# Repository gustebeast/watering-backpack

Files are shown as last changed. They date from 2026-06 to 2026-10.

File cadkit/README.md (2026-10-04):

# cadkit

Small, project-agnostic helpers for **parametric 3D-printing with CadQuery** — the
shared code behind a set of printable-hardware projects. Vendored into each project via
`git subtree`, so every project repo stays self-contained.

## Layout

```
cadkit/
  fasteners.py       M2/M4 hole + heat-set-insert geometry (self-tap now, insert later);
                     one FastenerSpec API, print-undersize aware
  threads.py         self-supporting 45° FDM screw threads (read THREADS_README.md first)
  joinery.py         printable mortise-and-tenon slide joints (read JOINERY_README.md)
  supports.py        teardrop + 45° wall-ramp support for short SIDEWAYS bosses
                     (horizontal cylinder off a wall, printed -Z→+Z)
  holes.py           teardrop_hole() — cutter for SIDEWAYS round holes: 45°
                     teardrop ceiling replaces the sagging round top; round
                     lower half untouched (pins/rods bear as in a round bore)
  printing.py        FDM minimum-material rule, counted in WHOLE BEADS (no
                     buffer — Arachne fills exact nozzle multiples cleanly).
                     min_wall(nozzle) = one bead = the hard floor;
                     min_wall(nozzle, beads=2) = 1.6 at 0.8 = the QUALITY
                     target. Aim at two; drop to one only in a tight room.
  contact.py         minimal-contact rub features: contact_rib_size(nozzle)
                     = exactly one nozzle (width AND proud; Arachne keeps
                     exact-nozzle lines); contact_ring() = ring + teardrop tail
  pcb.py             PCB mounting (one-screw cradle) + drawing-accurate JST headers
  board_geom.py      a ROUTED KiCad board as CAD solids: laminate, part bodies,
                     through-hole tails, mated plugs, connector mouths, silk
                     (read PCB_README.md first)
  board_check.py     gate: is the board the CAD draws the board that was routed?
  kicad_geom.py      KiCad-side exporter (run under KiCad's Python): routed
                     .kicad_pcb -> <board>.geom.json, the file board_geom reads
  kicad_silk.py      KiCad-side labeller: board name + revision, test-pad nets,
                     connector pinouts, each only where it fits
  pcbflow/           MAKE a board from code: one `elec/<board>.py` (SKiDL circuit +
                     placements) -> placed, autorouted, DRC-clean, labelled board,
                     its geom file and its fab package. gen.py (generator helpers),
                     layout/route/finish/verify/close_last, fab_package.py, example/
  PCB_QUALITY.md     THE standard PCB validation pass and the one place PCB lessons
                     go: automated rules (pcbflow/quality.py -- supply choke points
                     and drop, bypass capacitors, matched pairs, pinout citations)
                     plus a manual checklist each board signs with evidence
  step_export.py     export_step(obj, path) — names the STEP product after the file
  overlap_check.py   parallel interpenetration gate (wrap in tools/check_overlaps.py)
  cq_colors.py       hex / 0..255 / name -> cq.Color, for baking colours into a STEP
  freecad/           OPTIONAL FreeCAD viewer hub (isolated so the core needs no FreeCAD)
    __init__.py        `from cadkit.freecad import show`
  tools/
    agent_sync.py    dev-only multi-agent git-worktree coordination CLI (run as a script)
```

The **core** modules depend only on CadQuery/OCP — no FreeCAD. The FreeCAD-specific
viewer lives in `cadkit.freecad` and is opt-in; `show()` never raises, so viewer trouble
can't break a build.

## Use

```python
from cadkit.fasteners import cut_anchor, M2, M4
from cadkit.threads import cut_thread, threaded_rod
from cadkit.joinery import PrintSpec, joint
from cadkit.step_export import export_step
from cadkit.overlap_check import run
from cadkit import cq_colors
from cadkit.freecad import show          # optional; opens/refreshes a FreeCAD viewer tab
```

A project vendors cadkit at its repo root and runs its build via `python -m` from there,
so `cadkit` is importable with no path hack.

## Vendoring into a project

```
git remote add cadkit https://github.com/gustebeast/cadkit
git subtree add  --prefix=cadkit cadkit main --squash    # first time
git subtree pull --prefix=cadkit cadkit main --squash    # to update later
```

## Changing cadkit — you MUST propagate to every consumer

cadkit is **vendored** (copied) into each project, so the copies **drift** the
moment the canonical repo changes — nothing forces them identical. Therefore a
cadkit change is not *done* when you commit it; it is done when every consumer
project has been re-pulled. **Never edit a project's vendored `cadkit/` in place** —
edit the canonical repo, then propagate.

The whole process is one command — **run it from the standalone canonical cadkit
checkout, after committing your change there** (it refuses to run from a project's
vendored copy):

```
py -3.12 tools/propagate.py        # pushes canonical, then re-pulls into every consumer
```

It pushes the canonical to its upstream (one source of truth), auto-discovers
every sibling project that vendors cadkit, and re-pulls the subtree into each.
A project with a **dirty** working tree is **skipped** (never auto-stashed) and
reported — commit or stash there, then re-run. The exit code is the number of
consumers *not* in sync, so `propagate.py` doubles as a gate: **0 means every
project is current.** Use `--dry-run` to preview, `--no-push` to pull only.

(The manual equivalent, per project, is `git fetch cadkit main &&
git subtree pull --prefix=cadkit cadkit main --squash` — but do not hand-run it
across N repos; that is exactly the step people forget, which is what drift is.)

See `THREADS_README.md` and `JOINERY_README.md` before changing threads or joinery —
both encode FDM-specific rules that fail silently if broken. See `PCB_README.md` before
putting a circuit board in a project: it holds the KiCad ⇄ CAD loop and the board-design
guidance (mounting, connectors, layout, pre-order checks) that no tool can enforce.

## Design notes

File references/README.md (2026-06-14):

# Reference geometry

Drop reference STEP files here. They're imported by `src/viz.py` and
appear in `assembly.step` for dimensional verification — they're never
exported as printable parts.

Expected files:

| File | Source | Purpose |
|---|---|---|
| `makita_battery.step` | [GrabCAD — Makita LxT 18V 5A Battery](https://grabcad.com/library/makita-lxt-18v-5a-battery-1) | Battery dock interface reference |

Files in this directory are not committed (large binary; license varies
by source). Each contributor downloads them from the linked source.

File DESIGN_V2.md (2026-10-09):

# Watering Backpack v2 — Architecture

Status: **architecture settled, detailed design not started.** Written 2026-10-03.

v1 worked but had three compounding problems: the pump lost prime constantly, sand
from the pumice wrecked flow and threatened the pump, and the wiring was hand-soldered
flying leads. This records what v2 changes and — more importantly — *why*, since most
of these decisions came from measurements that are easy to lose.

---

## The v1 problems, diagnosed

### Priming

**Symptom.** After ingesting air, the pump would not re-prime. Recovery required
forcing water into the green line by mouth, repeatedly.

**Root cause.** The 4-way valve had to be reachable while wearing the pack, so it sat
at chest height. That forced the water path up, down, and up again. A diaphragm pump
moves air poorly, so re-priming means evacuating the whole line — but every dip holds
a water slug, and each slug adds static head the weak air-pumping cannot overcome.
Pouring water in worked because it restored a continuous column instead of making the
pump fight slug by slug.

**The thing that reframes it:** air ingestion is not a fault to prevent. The watering
method (fill the liner, then drain it dry) ingests air at the end of *every single
retract*, by design. Re-priming is a routine operation, not an exception.

### Filtering

Pumice fines in retract (the worse case) and fertilizer sediment in dispense. The v1
filter was unreachable while worn, and sat next to electronics so it could not be
rinsed. Cleaning it drained the pump, which then would not re-prime — the two problems
fed each other.

### Flow geometry

3/8" ID tubing on a 3.0 GPM pump is **8.7 ft/s**; suction lines want 2–3 ft/s. Four
5/8"→3/8" reducers compounded it. Roughly 6 psi of avoidable friction, and on the
suction side that directly erodes the margin against cavitation.

---

## v2 decisions

### 1. Two pumps, no reversing valve

Two Seaflo 42-series pumps in anti-parallel, sharing both lines through tees:

```
                      ┌─── Pump A (tank→pot) ───┐
  Tank ──── tee ──────┤                         ├────── tee ──── Green line ──── wand
                      └─── Pump B (pot→tank) ───┘
```

One wand. The idle pump's internal check valves seal its branch when **nothing is
running** — validated in the v1 BOM note: *"diaphragm pump check-valves block flow
when off, no siphon."*

⚠ **That note does not cover the case this arrangement actually creates, and the
sentence above used to be written as if it did.** The v1 note is about a STATIC
system: gravity trying to push water out of a wand below the tank, which a check
valve holds. Anti-parallel is not that case. Plumbed head to tail, a running pump A
raises pressure at the tee that is pump B's *inlet* and lowers it at the tee that is
pump B's *outlet* — a differential in pump B's **forward** direction, which is the
direction its check valves exist to pass. Two pumps in *parallel* would see the
reverse differential the v1 note describes; anti-parallel inverts it.

The risk is therefore not a siphon but a **bypass**: part of pump A's flow
short-circuiting through pump B's chambers instead of going down the wand. What
limits it is that a stopped diaphragm pump is a poor flow path, and nothing here has
measured how poor. **Built without a check valve, deliberately** — the cure costs
pressure drop, two more joints on a system whose headline problem is priming, and two
more air traps, against a fault that costs flow rate rather than function. The
measurement that would settle it is written down in `WORK_V2_PUNCHLIST.md` finding 12
so it does not have to be re-derived on the day.

**Why not reverse the pump:** a diaphragm pump's check valves are passive. Reversing
motor polarity spins the motor backwards but does not reverse flow. No diaphragm pump
is bidirectional; this is structural, not a sourcing problem.

**Why not solenoid valves:** cheap solenoids are pilot-operated and need 3–7 psi of
differential to open. At the moment of switching the differential is zero, so they
never open. Direct-acting valves work at zero differential but are expensive and draw
continuous holding power at this bore.

**Why not motorize the existing Farady X-port valve:** it is a car AC/heater valve,
designed for ~2 actuations per year. v2 would actuate it ~60 times per watering
session. It is already stiff enough to be hard to turn by hand after sitting, and dry
lube did not fix it — that is a duty-cycle mismatch of ~3 orders of magnitude, not a
lubrication problem. Motorising it relocates the failure to worn seats, stall
currents, and a sheared coupler. A purpose-built motorized ball valve is the same
ball-and-seat technology and would need two 3-way units (a 5/8"-barb motorized 4-way
X-port is not readily sourced), which needs the same two tees anyway.

Cost: **+$75, +~1.2 kg**, accepted.

**Open risk:** each tee has a branch to the idle pump. Those stay water-filled via the
check valves, but must be oriented so they cannot collect an air pocket. This system
ingests air every cycle, so air traps matter more here than in a normal install.

### 2. Flip the orientation — tank above pumps

Not mainly about flooding the inlet. A **dry diaphragm chamber primes terribly; a wet
one primes well.** Tank-above-pump keeps the chambers wet between sessions, which
attacks the root of the re-prime problem.

Note the limit: with the pumps fed from the tank only in dispense, retract still lifts
from pots at knee height (~1.5–2 ft). Flipping solves dispense priming structurally
and makes retract priming merely easier.

**Deck height is set by a hose, not by the pumps.** The rails sit at z=150, not
the ~124 that merely clears the 119 mm pumps. Pump B's inner port has its swivel
nut reaching into pump A's half, so that line cannot run forward at port height
without passing through pump A — measured at 8190 mm3 by `tools/check_plumbing.py`.
Its only way out is OVER the pumps, and a 19 mm line needs 9.5 mm either side of
its centreline. The alternative was a ~21 mm gap *between* the pumps, which buys
the same clearance out of WIDTH; width is the scarce axis (the posts already
overhang the 340 mm shelf) and height is not, so it came out of height.

### 3. Tank outlet — Uniseal

The Scepter's 44 mm opening is too small to get a hand inside, so a conventional
bulkhead (nut on the inside) is out. A **Uniseal** installs entirely from outside:
drill, work the seal in, push rigid pipe through. Standard on IBC totes and sealed
barrels, and holds far more head than 5 gallons. Scepter walls are flat enough.

Fallback if the Uniseal does not suit: keep the top-routed dip tube and add a **foot
valve** at its bottom so the column cannot drain back. Less robust — a slightly leaky
foot valve loses prime overnight — but needs no modification to the tank.

### 4. Filter — two bought strainers at the tees, self-backflushing

**DECIDED 2026-10-05.** This section used to specify a *printed*, sealed,
self-backflushing screen on the green line, and `src/line_filter.py` built it. It is
now **the two 50-mesh inlet strainers that came with the pumps, one at each tee** —
`WORK_V2_PUNCHLIST.md` findings 13 and 13a, both closed. The argument below did not
change; what changed is that the owner backflushed one of the stock strainers and it
cleared itself, which is this section's own argument made about the *exact part*
rather than about a part like it. The printed screen, its housing, and the
`test_screen_slice` coupon are gone — recorded in `bom_consolidated.md` §7b and its
*Dropped* list.

#### Why a filter on the green line at all, and why it self-cleans

The green line is the only line that is *both* bidirectional *and* connected to every
dirty source:

| operation | path | filter direction |
|---|---|---|
| retract from pot | sand → filter → pump → tank | filtering |
| fertilizer draw | fertilizer → filter → pump → tank | filtering |
| dispense | tank (pre-filtered) → pump → filter → pot | **backflushing** |

So the pump never sees unfiltered water, and **every fill backflushes what the
previous drain collected.** Sand migrates forward one pot per cycle — pumice fines
returning to pumice — and never accumulates. No cleaning step between pots.

**Geometry is constrained by backflushing, and the stock strainer satisfies it.** A
Y-strainer or spin-down collects debris in a sump *below* the flow path, deliberately,
so reverse flow does not re-entrain it — those filter and never self-clean. What is
needed is a straight-through cylindrical screen with no dead volume, which is exactly
what the 51S01 is, and the owner's backflush test is the proof rather than the
expectation.

#### Where they go, and which way round

One at each tee, inline on the tee's third leg: the green tee's leg down to the wand,
the tank tee's leg up to the Uniseal. Not dangling on the hose — that snags and adds
a suction-side joint that can pull air.

⚠ **They are DIRECTIONAL, and the handedness is set by the paragraphs above.** The
51S01 filters male→female and cleans female→male (owner, measured on the part). The
filter must collect on the drain and be swept clean on the fill, so the **male** end
faces whatever each strainer protects against — and that is not the same side at the
two tees:

- **Green tee: male toward the POT.** Dirty water enters at the wand on retract, so
  retract collects and dispense sweeps the debris back out toward the pot.
- **Tank tee: male toward the TANK.** What that one protects is **pump A**, and what
  threatens pump A is the tank's own settled sediment, drawn in on fill. So fill
  collects and drain sweeps it back into the tank to settle out again.

Either one fitted backwards runs its collecting stroke as a cleaning stroke and sweeps
the debris *toward* the pump instead of away from it.

Both therefore show their **female** end to the tee, and that is what makes the
fittings come out even — one male-threaded tee leg screws straight into each, with no
adapter and no hose stub. Worked through, with the fitting on each end, in finding 13a.

#### What the change costs, named

- **50 mesh instead of ≈60 mesh.** The printed screen's 0.25 mm slots were slightly
  finer than the strainers' 50 mesh. Accepted: the thing being excluded is pumice sand
  and fertilizer grit, and one mesh step does not decide whether the pump survives it.
- **Two tees have to be bought** — barb × barb × 1/2"-14 MNPT, 1/2" barbs. They were
  never on the BOM anyway (finding 14, closed), so this decision is what finally put
  them there rather than an extra cost it created.
- **The strainers' length is not measured, and it now matters.** Each one occupies
  inline length on its tee's third leg. The model gives the green leg 124 mm of
  straight and the tank leg about 100 mm. Finding 16.
- **No longer sealed.** The printed housing was deliberately unopenable, because a
  threaded joint on a suction line is an air-leak path and priming is the headline
  problem. Each strainer adds two threaded joints on a suction line. Accepted, and it
  is the real cost of this change: they are tapered pipe threads with tape, not the
  twist-off cap the argument was against, and the system already re-primes every cycle
  by design. Watch these two joints first if priming regresses.

**Spigot water** goes to the tank through its own separate fill line and bypasses the
filter entirely; municipal water is clean enough. Revisit only if filling from a rain
barrel.

**Barbs: 3/8" on the pot side** (fixed by the inner-pot tube), **1/2" everywhere
else**. The transition is the owned McMaster 5346K56 (1/2 NPT female × 3/8" barb) on
the green strainer's male end — the job the printed housing used to do. (This said
5/8" until 2026-10-05; see §5.)

### 5. Tubing — 1/2" everywhere except the probe

The 3/8" constraint is only the probe that goes down the inner-pot channel, and that
one is the owner's: *"the green line has to stay 3/8 but all the other lines can
change."* The main run is **1/2"**.

⚠ **This section used to read "5/8" everywhere except the probe" and it was wrong
by the time anyone read it.** The 5/8" was an inference from the friction argument
— nobody ever asked for it — and §2 of `bom_consolidated.md` had already decided
the other way, with reasons, when it chose the pump-port fitting. **The owner has
now bought that fitting**: SEAFLO SFFN1-1220-01, 1/2"-14 FNPT × **1/2" barb**,
five of them, four fitted and one spare. A 5/8" tube does not grip a 1/2" barb, so
the main run is 1/2" and the question is closed by a purchase rather than by an
argument. The contradiction had been sitting in three files, flagged in two of them.

**The numbers, so the trade is on the record rather than implied.** At 3.0 GPM:

| ID | velocity | friction vs 3/8" |
|---|---|---|
| 3/8" (v1) | 8.71 ft/s | — |
| **1/2" (v2)** | **4.90 ft/s** | **3.9× lower** |
| 5/8" (not taken) | 3.14 ft/s | 11.3× lower |

So 1/2" captures the large majority of the available improvement — friction goes
as roughly d⁻⁴⋅⁷⁵, so most of it is won in the first step up. **The residual, named:**
4.90 ft/s is still above the 2–3 ft/s a suction line wants, which 5/8" would have
reached. What makes that acceptable here is that v2's runs are short, the tank sits
*above* the pumps so the suction is flooded (§2), and the pump's own port bore is
~13 mm ≈ 0.51" — the ports are a 1/2" restriction whatever the hose is, so 5/8"
tubing would have bought its margin everywhere except at the four places the flow
actually has to squeeze through. "One reducer instead of four" — the old §5's
headline claim — was exactly backwards: with 1/2" barb swivels on both ports of
both pumps, going 5/8" needs a step at **all four**.

### 6. Electronics — one PCBA

v1's hand-soldered flying leads are a latent failure on something carried, shaken and
splashed. v2 is a single assembled board; the joystick and level sensor stay as the
modules they already are, on connectors.

**The two-pump decision deletes the H-bridge.** Each pump now runs in exactly one
direction — direction is chosen by *which pump is energised*, not by polarity. So each
needs a single switched leg, not four quadrants: one N-channel MOSFET + gate driver +
Schottky freewheel diode. A BTS7960 half dissipates ~0.9 W at 7.5 A; a 3 mOhm 40 V FET
dissipates ~0.17 W. Both of v1's hot parts (buck and bridge) are gone.

**Main board**
- 2x MOSFET pump drivers (40 V, low Rds(on), DPAK on copper pour; gate driver, not a
  bare GPIO, at 7.5 A and 20 kHz). Plain Schottky freewheel rather than synchronous:
  it only conducts during off-time, and usage is mostly full-on.
- 18 V -> 3.3 V buck, **LMR14020SDDA**, 0.6 A drawn of a 2 A part. Rated **>= 36 V in**
  — a fresh Makita pack is 21 V and inductive spikes exceed that, so common 24 V-max
  parts are too close to the edge. Single stage; this also deletes the Traco TSR.
  ⚠ **NOT synchronous**, which this line claimed for months and which nearly cost the
  board. The LMR14020 has one high-side switch and needs an external **catch diode** —
  D6, a 60 V 3 A SMA Schottky — because without it the SW node is driven past its -3 V
  rating every cycle and there is no 3.3 V rail at all, so no MCU, no joystick and no
  gate drive. It was found by reading the datasheet's layout figure against the placed
  board rather than by any check, because nothing on a schematic looks wrong when a
  part is simply absent. The inductor is **10 uH / 4.6 A saturation**: the first choice
  saturated below the regulator's own 3.8 A current limit, and the fix ran *down* in
  inductance. Output capacitance is C4 + C19 = 44 uF nominal, which is what the
  datasheet's equation 13 needs once X7R's DC bias derate is allowed for — the
  dielectric is a stated requirement, not a preference, because the derate is the whole
  argument.
- ESP32-WROOM-32E module (crystal, antenna, shielding, FCC pre-cert; bare silicon buys
  nothing here)
- Battery voltage divider -> ADC: duty compensation as the pack drains, and sag visible
  in telemetry
- **Active magnetic buzzer** + small transistor (its ~30 mA is beyond a GPIO) for the
  tank-full alert. Not a speaker — that would need an amplifier. Filling happens with
  the pump OFF and the user standing at the tank, so ~85 dB is ample.
- Tank level input: 3.3 V pull-up for the sensor's open-collector output
- **RC filter on the joystick ADC input** — the only noise defence available, since
  there is no joystick board to buffer at the source
- TVS (**SMCJ24A**, 38.9 V max clamp — same clamp as the SMBJ24A it replaced, 1500 W and 200 A IFSM instead of 600 W and 100 A) and bulk electrolytics near the switches. The package was chosen by the reverse-polarity sum, not the transient one: see `elec/CIRCUIT.md` §6.
  ⚠ **The reverse-polarity P-FET is NOT on the built board.** It was called optional
  because the battery inlet was keyed; the inlet is now a screw terminal, which is not.
  The consequence and the backstop are written up in `elec/CIRCUIT.md` §6. It is
  **closed**: the crowbar is sized by I²t against the fuse, and the fuse is **F2 on
  the board** now rather than a holder in the lead, so the sum rests on a part this
  repo contains instead of on a condition imposed on whoever wires it up.
- **F2, a 10 A ATC blade fuse on the board** — Littelfuse 178.6165 FLR holder taking
  the ATC blade already owned (McMaster 7460K45). It cost 12 mm of board length and a
  bay re-layout; what it bought is that the reverse-polarity argument above is now a
  **board property**. What it gives up is protection of the dock-to-board harness,
  which is short and inside the sealed bay. **C21**, 10 µF at the pack pad, is the
  only charge in front of it.
- **F1**, a 30 V 200 mA resettable PTC, in series with the level sensor's VBAT feed —
  that lead leaves the sealed bay and climbs the outside of the case, so it is the one
  conductor that gets rubbed and pinched, with a Makita pack behind it.
- 6-pin programming header with DTR/RTS. **No USB-C** — a connector is a water-ingress
  path outdoors, and OTA covers everything after bring-up. Its silk reads
  `3V3 / GND / ESP_TX / ESP_RX / EN / IO0`: the old `TXD`/`RXD` matched every adapter's
  own labels, so wiring like-to-like wired output into output.
- Connectors — **screw terminal blocks, not XT30 or JST** (the reasoning is
  `elec/CIRCUIT.md` §7). ONE family across all five: Ningbo Kangnex WJ500V-5.08,
  5.08 mm throughout — 2-pin for J1/J2/J3 (pack, pump A, pump B), 5-pin for J4
  (joystick), 4-pin for J5 (level sensor), on Phoenix MKDS-3 footprints whose
  F.Fab outline is a strict superset of the WJ500V body. J1-J4 all leave the
  board's -Y edge, which faces down in the housing; J5 and J6 are on +Y.
  The earlier split (MKDS-3 screw for power, PT-1,5 3.5 mm push-in for signals)
  is gone: the user's requirement is any no-solder wire attachment, and two
  families bought one vibration property at the cost of a second drawing, a
  second wire range and a second entry-face rule.
- Optional: low-side shunt per pump -> ADC (would have diagnosed the v1 slowdown
  immediately)

**Joystick: keep the existing KY-023 module.** Measured noise on battery is sd 7-9
counts, which is healthy — the ~120-count noise that cost a session to diagnose was a
USB-tether artifact, not the wiper. There is no measured fault to justify replacing it.

Rejected, and why: a **hall-effect thumbstick** would remove wiper wear, but the fault
it fixes has not been observed here. **Industrial hall sticks** (APEM TS series) are
$120 with a 12-week lead. **An encoder + printed lever** would be fully reflowable and
sealed with a digital output, but cannot match a gimbal's compact bidirectional spring
return — and a printed flexure *creeps*, which would reintroduce centre drift, the exact
symptom that opened this investigation. Hall thumbsticks are also consumer repair parts,
not distributor stock, so none of this is PCBA-assemblable anyway.

**Wire all five KY-023 pins** even though only VRy is used — it costs nothing and leaves
SW available as a mode button. The 2.54 mm housing on the module end does not latch, so
**the printed mount must capture the connector** so it cannot vibrate loose. That is the
real fix for v1's flying leads; a new PCB was not required to get it.

### 7. Tank level — single full/not-full, non-contact capacitive

An **external capacitive sensor** (XKC-Y25 class) clamped to the *outside* of the tank
wall at the full line. Nothing penetrates the tank and nothing touches the water, which
sidesteps the 44 mm opening entirely — the binding constraint on every other approach.

- Powered **directly from the battery rail** (5-24 V spec covers the pack's 15-21 V), so
  it needs no 5 V rail — important, since the board now only makes 3.3 V.
- Configure the output **NPN open-collector** and pull it up to 3.3 V on the main board.
  The sensor runs at 18 V but an open-collector output only pulls down, so the GPIO sees
  a safe level with no divider. Push-pull mode would put 18 V into a GPIO.
- Printed bracket clamping it flat to the wall; consistent contact matters more than
  force, since a gap shifts sensitivity. Scepter HDPE is a few mm, well inside the
  0-20 mm range.

**Mount it slightly BELOW the true full line.** False positives are cheap (stop early,
look, carry on) but a false negative means overflow, and capacitive thresholds drift
with temperature. Tripping early gives margin in the direction that actually costs
something.

Rejected: a conductivity probe needs alternating-polarity excitation to avoid
electrolysis and still fouls as fertilizer salts film the electrodes — it drifts rather
than fails, so it would be diagnosed twice. A float switch is more reliable than either
but must pass through the 44 mm opening and needs a sealed-ish top plug. Non-contact
won on assembly simplicity, with the false-positive risk accepted explicitly.

This also simplifies the top plug back to just **vent + spigot fill line**.

### 8. Firmware

The joystick finally works as originally intended: **forward = dispense, back =
retract**, because direction is now an electrical choice rather than a hand-turned
valve. Remove the forward-only restriction added in v1.

Carry over from v1, all of it still relevant: the K-of-N engage vote, hysteresis,
median-based centre calibration, WiFi telemetry, OTA, and the persistent disarm.

---

## What checks this design, and what each one is for

Fifteen gates. Every one of them exists because something it now catches had already
got through, so the list below says what each was *written for* rather than what
it nominally covers. All exit non-zero on failure, so any of them works in CI.

`py -3.12 -m src.build` runs seven of them itself:

| gate | written because |
|---|---|
| overlap | parts that interpenetrate. The whitelist is three entries and each carries its measured volume; three more were dropped once measuring showed they were whitelisting 0.0 mm³ — i.e. standing ready to hide the first real clash |
| battery access | the pack could not be lifted out. It fits in the dock, and that is not the same thing: it needs 93 mm of lift |
| install/removal | the same question for the lid and the contact block, both of which can fit where they end up and still be impossible to get there |
| pump mount | the pumps bolted to nothing at all. Checks all 8 holes are open, land in wood, and that the feet still touch the floor |
| board retention | checked BOTH ways, because one way is not a check: the board must not lift straight off (the +Y lip holds 21 mm³ of it) and must come out after sliding 2 mm toward -Y. A board that cannot be got out is one you cut up to reflash |
| board seating | the board must be WHERE ITS OWN MOUNTING HOLES ARE. It was not, on both axes at once, and neither error was an overlap: the ESP32's antenna overhang shifted it 2.06 mm off the drilled holes in Y and the lead tails floated it 3.4 mm clear of its bosses in X |
| routed-board agreement | the CAD must draw the board that was actually routed, not a typed placement. PCB_README: *"a hand-typed copy can only be checked against itself, and it always agrees"* |

Standalone:

| gate | written because |
|---|---|
| `tools/check_v2_overhangs.py` | it was checking 3 of the 5 parts shipped, and its classifier judged a 270° arc by one sampled normal. Now enumerates `printed_parts()` and takes the pose from there, so coverage and build direction cannot drift from the exporter |
| `tools/check_pin_map.py` | six GPIOs typed in three places — firmware, `elec/main.py`, CIRCUIT.md — with nothing requiring them to agree. Also enforces the ESP32 rules (ADC1 for analog, no outputs on 34–39, no gates on strapping pins) against the role the firmware *actually uses* |
| `tools/check_bom.py` | the BOM's volumes and cut list are generated fact written by hand. Both had gone stale within a day of the edits that moved them |
| `tools/check_pump_dirs.py` | "never both pumps at once" has to hold, not usually hold. Transcribes the firmware and fails if the C++ it claims to transcribe changed |
| `tools/check_plumbing.py` | a route that cannot be bent, or one that passes through something. Every hose-to-fitting contact now carries a MEASURED ceiling: the bare pair list it replaced was hiding a hose drawn curving through 45 mm of rigid elbow, sixty times its neighbours' reading |
| `tools/check_level_alarm.py` | the tank is carried on someone's back, so the sensor is crossed constantly. The debounce *is* the feature and a still bucket cannot test it. Check 9 also derives `LEVEL_FULL_IS_LOW` from the netlist, because the other eight take it as an input and passed with it set either way (finding 47) |
| `tools/check_part_values.py` | `main.cpp` asked for it by name: *"THIS CONSTANT IS A COPY OF A BOARD VALUE AND NOTHING COMPARES THEM … check_pin_map.py ties this firmware to the schematic, but only by PIN NUMBER"*. R21 had already gone 18k → 10k on the board with the firmware's copy left behind, which reads a 15 V pack as 8.94 V and falls back to the fresh-pack duty cap. Checks the firmware's copies against the netlist, every component value claimed in prose, the duty-cap figures `BRINGUP.md` tells an operator to expect, the pack range `CIRCUIT.md` publishes in its rail table, and that a slash pair like `R26/C22` names two parts that actually share a net — which is how C19, a 3V3 decoupler, was found standing in for the level filter |
| `tools/check_silk_face.py` | the board was PLOTTED in Rennie Mackintosh PSG and DRAWN in the CAD kernel's default face, and every gate passed for as long as that lasted — `cad_geom_check` counts labels by probing for ink where each is printed and read 139 / 139 throughout, because a label in the wrong typeface is still a label with ink in it. Checks that the declared face resolves on this machine, that the kernel actually applies it (otherwise nothing else means anything), that the installed file is the REDRAWN one and not ITC's original whose "+" is a TH ligature — both carry the same family name — that `src/housing.py` hands it to the Boards that draws, that `silk_cap` is the measured 0.6670 and not cadkit's 0.72 default, and that the face has a glyph for every character the board prints, since OCC silently substitutes another font when it does not |
| `tools/check_bead_grid.py` | every wall, plate, lid and skirt in the housing was 3.0 mm, which at a 0.8 nozzle is 3.75 beads — so Arachne, not the drawing, chose the section of every load-bearing wall in the part. Nothing had pinned a nozzle diameter at all. Off-grid lengths are allowed where AGENTS.md allows them, but each must name its kind (hardware / clearance / standards) and its reason, and the gate fails on an exemption that has gone stale as readily as on an off-grid wall |
| `tools/check_ic_pinouts.py` | a gate driver whose pinout was wrong on four of five pins, putting a GPIO on its supply and a 4 A output onto the 3.3 V rail — and every stage downstream agreed, because every stage downstream was derived from it. Checks pin maps against datasheet tables cited by document and page, each supply pin against its part's operating window, each rail against the voltage it is meant to BE (3.12 V is inside every part's window and still wrong), and every numbered pad on the routed board for a net — which is how two floating anode leads and the ESP32's whole thermal ground were found |

⚠ **AND ONE THING THESE GATES DO NOT DO: NONE OF THEM COMPILES THE FIRMWARE.** Three of them transcribe or derive from `firmware/src`, so they fail when the C++ text they quote changes — but a firmware-only edit that simply does not build passes every `tools/check_*.py` in this table. The build is verified by `cd firmware && pio run -e main-usb`, which is a **separate step and has to be run deliberately** (measured 2026-10-08: clean, RAM 16.0 %, Flash 78.3 % — 1,026,150 of 1,310,720 bytes of one app slot). A compile gate is deliberately NOT in the suite: it would need PlatformIO present, and a gate that SKIPS when its tool is missing is the `ok=None` defect finding 47 removed from A18 — counted as neither a pass nor a failure while printing as one. Better a named gap than a gate that lies. PlatformIO also refuses at link time if the image exceeds the app partition, so the size ceiling has an owner even though this table does not hold it.

Two habits go with them, and they matter more than the list:

- **A gate is not finished until it has been made to fail.** Every one above was
  verified by reverting the defect it was written for and confirming it bites.
  Two were found to be *vacuous* that way — asserts that could only ever check
  their own arithmetic — and one had a tolerance wider than the error it existed
  to catch.
- **Accepted findings are named and measured, never lumped.** The overhang gate's
  `ACCEPTED` table and `pcbflow`'s `pcb_declared.py` both list a specific feature
  with a reason it cannot be designed out. A single total teaches everyone to read
  the number as "fine".

---

## Open questions

0. **Measure the pump elbows — one caliper reading unblocks a 38.5 mm decision.**
   `ELBOW_LEG_L = 45` is an estimate, and pump B's INNER port is the one port on
   the machine with nowhere to go but up. The hose's first corner has to sit
   `BEND_R` above wherever the elbow leg ends, and the rails cap the centreline
   at 140.5:

   | | |
   |---|---|
   | port centreline | 84.0 |
   | elbow leg ends (at the estimated 45) | 129.0 |
   | first corner must be at | 179.0 |
   | rails cap it at | 140.5 |
   | **short by** | **38.5 mm** |

   This frame accepts a **6.5 mm** elbow leg on that port, and no such fitting
   exists. Either the real leg is far shorter than 45, or `RAIL_Z0` has to go
   from 150 to ≥ 188.5 — taller posts, and the deck and tank 38.5 mm higher.
   `RAIL_Z0` is already documented as being set by this hose, so option two is
   the design's own stated dependency, not a workaround. The frame is **not**
   being raised on the strength of an estimate. `tools/check_plumbing.py` pins
   the defect at its measured 9962 mm³ meanwhile, so nothing about it can move
   quietly.

1. **Confirm the buck thermal theory.** Run continuously into a bucket for 60 s and
   see whether it fades; if so, feel the buck (it will be hot). This decides whether
   deleting the buck actually fixes the slowdown or just removes a part.
2. **PCBA fab.** JLCPCB? Their assembly library constrains part selection enough that
   picking the fab after choosing parts means redoing work.
3. **Specific hall-effect joystick part** — not yet chosen. Selection criteria: output
   range compatible with a 3.3 V ADC, spring return to centre, single axis sufficient,
   footprint that suits a printed mount. It drives `joystick_mount.step`. It does **not**
   block board layout: the joystick comes in off-board on J4, a 5-pin terminal block, so
   the main board is indifferent to which part is behind it.
3. **Makita pack capacity**, for runtime estimates.
4. **Uniseal size** against the Scepter wall, once a panel is measured.
5. **Ramp / dose metering.** v1's 1000 ms ramp made "feather the trigger for small
   plants" work; it was reverted to 106 ms while chasing the slowdown. If the buck
   turns out to be the cause, the slow ramp should come back.

---

## Carried over unchanged from v1

Seaflo SFDP1-030-055-42 pumps (12 V, 3.0 GPM, 55 psi), Makita 18 V pack + 643852-2
terminal, Traco TSR 1-2450E for logic 5 V, KY-023 joystick, BTS7960, the 10 A ATC
fuse (its *holder* did not carry over — it is **F2 on the main board** now), Scepter
5 gal can, Stansport frame, separate spigot fill line.

**Dropped:** Farady 4-way X-port valve, Pololu D42V110F12 buck, 5/8"→3/8" reducers
(×4 → ×1). *The pump inlet strainers were on this list as "redundant given the
green-line filter" until 2026-10-05; they are now the green-line filter itself — §4.*

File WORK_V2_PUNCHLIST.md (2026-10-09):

# v2 punch list — from the 2026-10-04 CAD review

Nine items, raised against screenshots of `assembly_v2.step`. Each one is
closed only when a gate or a measurement says so, not when the code changes.
Status is maintained here; the reasoning lives next to the code.

| # | item | state |
|---|---|---|
| 1 | Lid needs a screw access path — the 45 ramp blocks the driver | **done** |
| 2 | Lid needs a skirt; 20 mm clear on all sides before the battery mount, -Z needs a wiring hole | **done** |
| 3 | Lid's 4 M4s and their inside bosses come out; wood screws hold it | **done** |
| 4 | The extra chunk at the wiring window is unnecessary — plain wall, then cut | **done** |
| 5 | Battery-mount wings are v1 joinery, dead in v2 (one side: Y 3.00..17.30) | **done** |
| 6 | The green water line makes a strange vertical jump | **done** (and it is a blocker — see DESIGN_V2 open question 0) |
| 7 | PCB retained by plastic on all sides but -X; drop to one M4 via cadkit's hole cutter; 45 ramp -X retention on +Y edge, slot-and-rotate install | **done** |
| 8 | Wiring window is not placed to reach the four blocks on the board's bottom edge | **done** |
| 9 | Port bronner's PCB debuggability work (test pads, silkscreen); re-audit the board end to end | **done** (twelve findings, a new gate, five cadkit bugs) |

## Notes on scope

* 1, 2 and 3 are one change: the lid stops being a flanged plate with its own
  M4s and becomes a shoebox lid retained by the two +X wood screws. The earlier
  "WHY THERE IS NO PERIMETER SKIRT" finding in `src/housing.py` measured the
  skirt as impossible **inward** (a -0.06 mm gap in Y) and as having nothing to
  lap **outward** over the bay footprint. The user's measurement says otherwise
  for the outward case: 20 mm of drop is clear on all sides before the battery
  mount. That finding has to be re-measured, not assumed.
* 7 changes the overlap and overhang baselines, so both gates get re-run and
  any whitelist entry that moves gets re-measured and re-named.
* 9 is a PCB audit, not a CAD change; it ends in `elec/` and the fab gate.
  It landed as **ten net-labelled bring-up pads**, **twelve findings** in
  `elec/CIRCUIT.md` (four would have stopped the board, one would have destroyed
  it), and `tools/check_ic_pinouts.py` — the gate the audit's own conclusion
  asked for, since *nothing in the pipeline checked a pin map or a voltage*.
  Adding the pads also flushed out **five bugs in cadkit**, each of which
  produced a board that read as clean: a search graded by a rule it did not use,
  a failed search that left a pad shorting VBAT to a GPIO, a use-after-free in
  `board.Remove()`, two vias in one hole, and a fab report in which an explicit
  "undecided" declaration lost to a footprint guess.

## Round 2

| # | item | status |
|---|---|---|
| 1 | Check the retractable-cable-spool project for its wood-screw head size; make sure the lid hole passes it | **done** — Ø9.3, and our countersink was Ø9.0 |
| 2 | Remove the diamond tie slots | **done** |
| 3 | Battery wiring on the plate's +X side needs a way in: a hole -Z of the PCB box, then a 90° turn +Z | **done** |
| 4 | Oversize the ±Z board stops by 2.4 mm; put 1.6 mm of square prism on the +Y ramp's tip | **done** |
| 5 | Why is a part hanging off the edge of the board? | **answered** — deliberate, see below |

### What the measurements said

**1. The screw is bigger than the hole was.** `retractable-cable-spool/src/params.py`
carries it as "v2's validated screw geometry, verbatim": shaft Ø4.0, **head Ø9.3**,
cone 4.0 deep. Two things followed. The housing's countersink was **Ø9.0 — three
tenths SMALLER than the head**, so the head would have landed on the pocket's rim
instead of seating in it; it opens Ø9.6 now. And the lid's access bore was Ø9.5,
which clears a Ø9.3 head by a tenth of a millimetre per side — a fit, not a hole
you post a screw down on the end of a long bit. It is Ø11.0 now, which in turn
forced the lid's countersink seat from 3.0 to 3.5 mm, because a 45° cone from
Ø11 to Ø4.5 is 3.25 deep.

The 45° pocket is the right shape and not a printing accident: its half-angle is
steeper than an 82° wood screw's, so the head contacts near the mouth and pulls
flush. A shallower pocket would bottom the head out and hold the plate off the post.

**3. The wire entry had a 7 mm window and all three edges were measured.**
Z ≤ 11.0 is the bay's -Z wall; Z ≥ 4.0 is the floor plank's top, measured off the
frame solid, below which the slot opens into timber; Y 121.7..172.0 is the chase at
one end and the +Y post's inboard face at the other. The slot is 22 × 5 mm at
Y 139..161, Z 5.5..10.5, and the 90° turn needs no pocket cut for it — the chase
already removes the bay's -Z wall across that whole Y band, so once the leads are
through the plate they look straight up into the bay. Verified by sweeping a Ø4
probe along both legs against the housing *and* the lumber: clear.

**5. Nothing is wrong — U2's antenna has to leave the laminate.** The ESP32
footprint's courtyard is not the module outline; it is a T-shaped polygon that
includes the antenna fan, and the matching keepout bans tracks, vias, pads, pour
**and footprints** inside it. So the fan has to hang off a board edge rather than
lie across the board, and rot 270 puts it over the +X edge where the only thing
left under it is a mounting-hole cutout, which a keepout does not forbid. The
module body overhangs by **4.12 mm**; every one of its castellated pads is still
over laminate. The housing already accounts for it — `BOARD_Y_PLUS` is taken from
the posed board's bounding box, not the laminate, which is why the bay cavity is
wider on that side than the board is.

### Notes

* The tie slots in #2 were the screw terminals' only strain relief. The battery
  pair does not miss them: #3's slot is a close fit through a 3 mm plate with a
  90° bend against it, which is relief for the one pair carrying 7.5 A. The leads
  arriving *down* the chase from the tank side still have none, and `src/housing.py`
  now says so in as many words rather than leaving the absence to look deliberate.
* #4's stops reach 2.4 mm past the laminate's top face, leaving 17.1 mm of air to
  the lid. The retention gate's reading went from 21 mm³ of lip in the way to 88.
* The overhang gate caught a bug in #3 before the build did: the slot was extruded
  the wrong way down +X and cut a 0.5 mm blind pocket in the back of the plate
  instead of a through hole, which it reported as 104.6 mm² of flat ceiling.

## Round 3

| # | item | status |
|---|---|---|
| 1 | Make the lid opaque | **done** |
| 2 | One of the pumps is translucent too | **done** — same cause |
| 3 | Is there room for the PCB→motor wiring as well? | **done** — there was, barely; widened |
| 4 | What are the blocks on the PCB underside? | **answered** |
| 5 | Walls should be bead-width multiples, not 3 mm | **done** |
| 6 | Why doesn't the screw boss line up with the wall? | **done** — it can't, so the plate closes the gap |

**1 and 2 were one bug.** The viewer's alpha rule was
`0.35 if battery else 0.85 if "_" in nm else 1.0`, and an underscore in a name is
not a reason to see through something. It caught `housing_lid` — so the one part
whose job is to close the bay was drawn translucent, and every screenshot of the
board was taken *through* it — and `pump_a`, `pump_b`, `pcb_screw_0` and
`pcb_insert_0` as well. See-through is declared now, and only the battery (and
the tank, which always was) is.

**3. There was room, with nothing to spare.** Every terminal is on the board's
bottom edge and the chase is the bay's only exit, so J1's battery pair *and*
J2/J3's two pump pairs all come down the chase and all cross the plate — six
conductors, with the pumps 65 mm further +X again. At 14 AWG for the battery and
16 for the pumps that is 17.8 mm laid side by side, and a 5 mm slot is one layer
deep, so width is what carries them. The 22 mm slot held exactly six with no
slack and no room to be wrong about gauge. It is 40 mm now (Y 127..167), still
inside the measured Y 121.7..172.0 window.

**4. Through-hole lead tails.** Nine footprints have them — J1–J6, the buzzer,
and the two ICs' thermal vias — drawn 3.4 mm proud of the solder side. They are
the reason `STANDOFF` is 4.0: the tails end 0.6 mm short of the bay floor, and a
shorter standoff would stand the board on its own solder joints.

**5. Nothing had pinned a nozzle.** `src/housing.py` is on the bead grid now at
`NOZZLE_D = 0.8`: walls, lid and skirt 2.4 (3 beads), the back plate 3.2 (4 — the
extra bead is the countersink's, since a 2.55 mm cone would break clean through a
2.4 plate). The lid lost 15 cm³. `src/battery_dock.py` stays off-grid as hardware,
on the user's point that it has to match the pack and the Makita adapter.

**6. Those two walls can never line up.** The boss is placed by the SCREW, which
is on the post centreline at y=191; the skirt is placed by the BAY it laps, whose
outer face is at y=204. Nothing can bring them together. What was wrong was the
carried-up plate strip stopping at the boss's own face, leaving an 8.4 × 13.6 mm
notch between two walls that look like they should meet. The strip runs to the
lid's +Y edge now, so the boss ties into the skirt corner instead of cantilevering
off a tab — which matters, because that boss takes the lid's whole retention load.

## Round 4

**The step at the lid's screw boss.** Two faces, one cause.

The 81.6 mm² face is the boss's **underside**, over the 5.1 × 16 mm of it that
reached past the skirt's end to the back plate. It could not "extend a few mm
−Z": the housing's bay +Z wall sits **1.6 mm** below it in the same X band, so a
few millimetres of −Z and the lid will not go on at all.

The step was never about Z. The boss's X limit and the skirt's X limit are set by
different jobs and can never be the same number:

- the boss **must** touch the back plate — the screw clamps lid, plate and timber
  in one stack, and a gap there is a gap the lid rocks through;
- the skirt **must not** — the lid seats on the bay **rim**, and a skirt that
  bottoms out on the plate holds the lid off the one joint that is under five
  gallons of water.

The gap between those two limits *is* the step, so the fix is to make it small
rather than to remove it. Measured: the bay is 25.1 mm deep, a test skirt clears
the dock, the pack and the timber at 25.1, and fouls the plate at 26.0. The skirt
is **24.0** now (30 beads) — the last whole bead short of the plate. The lid
closes on 1.1 mm of gap and the step drops from **81.6 mm² to 17.6**.

A new assert holds it: the skirt must stay ≥ 1.0 mm clear of the plate. Nothing
downstream would have caught that one — every part still fits and the install
gate still sweeps clear while the lid quietly closes on the wrong face.

**The 115.4 mm² face is the strip, and it is load-bearing.** It is the piece
added in round 3 that carries the lid plate up behind the boss. Without it the
boss hangs off the plate by the 1.2 mm of Z where the two overlap — for the one
feature that takes the whole lid's retention load. The 7.8 mm of it beyond the
boss's own face is what ties it into the +Y skirt corner. Say the word and it
comes off, but it is doing a job.

## Round 5 — two open decisions the board cannot take for itself

Both came out of reading the **exported gerbers** against the design documents,
and neither is a bug in the board: the board is at 0 unconnected, 0 DRC
violations and 0 quality FAILs, and it is orderable as it stands. They are
places where three documents promise something the built board does not have,
and where the change needed is big enough that it is the user's call.

| # | item | state |
|---|---|---|
| 10 | **No reverse-polarity protection on VBAT**, which `CIRCUIT.md` §6, `DESIGN_V2.md` §6 and `bom_consolidated.md` §6 all said was there | **RESOLVED** — D1 SMBJ24A → SMCJ24A |
| 11 | **The pack and both pump terminals are SCREW**, where the same BOM line argues for spring-cage on a frame shared with two motors | **RESOLVED** — clamp style is free; all five are now one screw family |

**10 is RESOLVED, and the thing that was wrong was this item's own framing.**

The P-FET was written down as "insurance rather than necessity, *because the
Makita terminal is keyed*". That was sound while the inlet was a keyed XT30.
`CIRCUIT.md` §7 then replaced it with **J1, a 5.08 mm screw terminal carrying two
identical wires** — the single easiest thing in the machine to land the wrong way
round — and nobody came back to §6. The board was built from the connector
decision; the protection decision was never re-opened. No gate on this project
can see that, and it is worth being precise about why: every gate reads the
**board**, and the claim lived in **prose**.

**What this item got wrong: it assumed protection meant a SERIES element.** That
is what made it look expensive — a series P-FET splits the VBAT pour into two
islands bridged by the part, a re-layout of the board's highest-current path on a
board at zero findings — and it is why the only alternative on offer was
restoring a keyed inlet, which contradicts §7 *and* the user's own requirement
for a no-solder screw terminal. Both options were bad because the question was
posed wrongly.

Reverse-polarity protection by **crowbar is a SHUNT**. D1 already is one: a
unidirectional TVS across VBAT–GND, on a pour and a ground plane that both
already exist. Nothing needs splitting. The only real question is whether the
part survives the job — and that is arithmetic, not layout.

**The arithmetic, and why it is I²t.** The fault current depends on the pack's
internal resistance, which is not in this repo. I²t removes that unknown: the
fuse clears on charge delivered, the diode dies on charge absorbed, both are I²t,
and the smaller one goes first at *any* fault current.

| | I²t | |
|---|---|---|
| D1 as built, **SMBJ24A** | 100 A IFSM @ 8.3 ms → **83 A²s** | loses by 1.4× |
| the fuse, **Littelfuse 257-010** 10 A ATO | **115 A²s** min. melt | |
| D1 now, **SMCJ24A** | 200 A IFSM @ 8.3 ms → **332 A²s** | **wins, 2.9×** |

⚠ The first pass at this got the answer **backwards**. Guessing "a 10 A blade
fuse is about 50 A²s" put the fuse first and had D1 survive as built. The
published minimum is 115, and the conclusion reversed on a number that was looked
up instead of remembered. The fuse figure is cited for that reason.

**The fix was one footprint.** SMCJ24A is the same TVS one package up: clamp
**38.9 V at 38.6 A, identical** to the SMBJ24A's (checked across five makers), so
nothing downstream of the clamp moves; 1500 W against 600 W; 200 A IFSM against
100 A. `D_SMB` → `D_SMC`. No series element, no split pour, no keyed connector.
`elec/main.py` carries the derivation and asserts `TVS_I2T_MARGIN > 1.5`.

**Residual, named and measured rather than lumped.** A reversed pack still runs
current backwards through each pump winding via D2/D3 and the FETs' body diodes
until the fuse opens, so the pumps briefly suck on the pressure line, and C1/C2
sit reverse-biased at D1's forward drop for that time — milliseconds, and neither
is a damage mechanism.

⚠ **AND THE FUSE IS ON THE BOARD NOW**, which is the second half of this item and
was closed after it. While the fuse was a holder in the lead, the sum above rested
on a part this repo did not contain. **F2** — Littelfuse 178.6165 FLR holder, LCSC
C207061, taking the 10 A ATC blade already owned — puts it on the laminate in series
with D1. The board grew 100 → 112 mm for it and the housing bay was re-laid; what
was given up is protection of the dock-to-board harness, which is short and inside
the sealed bay. Do not fit a larger blade: **115 A²s** is the ceiling this sum is
built on, and a larger one silently re-opens the finding.

**11 is RESOLVED.** The user's requirement is narrower than the punchlist
assumed: *any* way to land a wire without soldering, with no preference between
screw and spring cage (a JST crimp was specifically rejected as more hassle than
either). So the clamp style stopped being a constraint, and the board went the
other way from what this item proposed — to **one family, all screw**: Ningbo
Kangnex WJ500V-5.08, 2P/4P/5P. The asymmetry this item complained about is gone
because the split is gone. See `elec/CIRCUIT.md` §7 for the withdrawn preference
and for the 16.9 K rise that replaces "31 % of contact rating".

⚠ This section used to end *"10 is still open and no longer has 11 to hide
behind"*. Both are resolved now; the sentence is removed rather than left to
contradict the table two screens above it.

---

## Round 6 — the plumbing, which the board work had been walking past

Neither of these is a board finding. Both are **decisions the owner has already
taken**, written down here because the design documents still say something
else — which is the same failure mode as finding 10: a claim that lives in
prose, where no gate can reach it.

| # | item | state |
|---|---|---|
| 12 | **§1's "the idle pump's internal check valves seal its branch" does not cover the case that matters.** | **OPEN** — built without a check valve, deliberately; the test is written down below |
| 13 | **The printed line filter vs the two strainers that came with the pumps.** | **OPEN** — fully specified now; one purchase decision left, and it is the owner's |
| 14 | **The two tees §1 has always needed are not on the BOM at all.** | **OPEN** — size settled at 1/2"; the thread depends on 13 |
| 15 | **DESIGN_V2 §5 called for 5/8" tubing that §2 of the BOM had already decided against.** | **RESOLVED** — 1/2", settled by the fitting the owner bought |

### 12 — the idle pump sees a FORWARD differential, not a reverse one

§1 cites the v1 BOM note, *"diaphragm pump check-valves block flow when off, no
siphon"*, and that note is about a **static** system: no pump running, tank
above the wand, gravity trying to push water out. A check valve holds that.

The anti-parallel arrangement is not that case. The two pumps are plumbed
**head to tail**, so when pump A runs tank→pot it raises pressure at the tee
that is pump B's **inlet** and lowers it at the tee that is pump B's **outlet**.
That is a differential in pump B's **forward** direction — the direction its
check valves are built to pass. Two pumps in PARALLEL would present the idle one
with a reverse differential, which is the case the v1 note covers; anti-parallel
inverts it.

So the worry is not a siphon. It is that part of pump A's flow short-circuits
through pump B's chambers back to the suction tee instead of going down the
wand. What limits it is that a stopped diaphragm pump is a poor flow path — the
diaphragms are held by the motor's cogging and the chambers are small — but
"poor" is not "none", and nothing here has measured it.

**Decision: build it without a check valve.** The owner's words: *"what if I
skip the test and just build it with no check valve"*. That is reasonable — the
cure (two check valves in a 5/8" line) costs pressure drop, two more joints on a
system whose headline problem is priming, and two more air traps, and the fault
it guards against is a loss of flow rate and not a failure to work at all.

**The test, so it does not have to be re-derived on the day.** With the wand in
a bucket and the tank full, run pump A at RUN_DUTY and time a measured volume;
then clamp pump B's two branch legs shut and repeat. The ratio is the bypass
fraction. Anything under about 10 % is not worth a valve. If it is large, the
cheapest fix is not a check valve either — it is a pinch clamp on the idle
pump's branch, which the firmware already knows which one is idle.

### 13 — the strainers that came with the pumps, at the tees

> ✅ **CLOSED 2026-10-05 — the owner decided: "Let's go with the two MNPT tees,
> skip the printed screen."** What that changed in the repo is listed at the end
> of this finding.

§4 designs a printed 1" wedge-wire screen on the green line and says the pumps'
own 50-mesh inlet strainers are redundant. The owner has since tested one:
*"I tested the one that came with the pump and it cleaned itself when run
backwards. I'm thinking we should just put the two filters at the T's on the
merged end."*

That is the same backflushing argument §4 makes for the printed screen, now with
a **measurement behind it** rather than a prediction — and it is a measurement
of the exact part, not of a part like it. Two strainers at the two tees also sit
where §4 wants filtration (everything upstream of a pump is filtered) without a
printed consumable in a sealed line.

**The topology works, and `src/plumbing.py` already settles which leg.** Each tee
has three legs: two to the pumps, and one shared — `TANK_TEE`'s third leg goes up
to the tank, `GREEN_TEE`'s goes out to the wand. A strainer in a *shared* leg sees
flow both ways:

| | tank tee's shared leg | green tee's shared leg |
|---|---|---|
| dispense | tank → tee, **filtering** | tee → wand, **backflushing** |
| retract | tee → tank, **backflushing** | wand → tee, **filtering** |

So both strainers self-clean on alternate strokes, which is §4's own argument run
twice. A strainer in a *pump* leg would not: those legs are one-directional, so one
would only ever filter and the other only ever backflush.

**The thread is settled now, and the owner's instinct was right.** Seaflo's own
page for the 51S01 (the strainer that ships with the 42-series pump): **1/2"-14
MNPT one end, 1/2"-14 FNPT the other**, 50 mesh, PA, removable clear top. So:

- the tee the owner asked for — *"two barbed fittings and one male thread"* —
  screws straight into the strainer's **FNPT** end. That ask is exactly right and
  a barb × barb × MNPT tee is a stock part;
- the strainer's **MNPT** end then wants a female barb, and the BOM already carries
  that family: SEAFLO SFFN1-1220-01 is 1/2"-14 FNPT × 1/2" barb, O-ring sealed,
  nylon — bought for the pump ports, and the 5-pack already has a spare.

**All three of the things that used to block this are answered.** They were the
tubing size, the 3/8" transition, and the mesh.

1. ~~The tubing size is not settled~~ — **1/2"**, finding 15 below. So the tee is
   a **1/2" barb × 1/2" barb × 1/2"-14 MNPT** tee, and nothing about the size is
   open any more.
2. ~~The printed filter is also the 3/8" → 1/2" transition~~ — it is, and the
   answer is a **single 1/2" × 3/8" barb reducer at the probe end of the green
   line**. That is *not* the v1 mistake: v1's sin was four reducers necking the
   whole system to its narrowest element (DESIGN_V2 §4), and this is one, at the
   end, on the section the pot fixes at 3/8" anyway.
3. **Mesh, accepted and named rather than resolved away:** §4's screen is 0.25 mm
   (≈60 mesh) and the strainer is 50, so the change is **slightly coarser**. §4's
   own sizing is driven by face velocity and open area, not by particle size — the
   number it argues for is 0.96 in² of open area at ≤1 ft/s — and 50 mesh is still
   finer than anything a pumice pot sheds that a diaphragm pump would mind.

### 13a — the strainer is DIRECTIONAL, and that decides which fitting goes where

> ✅ **CLOSED 2026-10-05** with 13, which it was the sourcing half of. The
> orientation conclusion below is now what DESIGN_V2 §4 says, not a proposal.

The owner, 2026-10-05: *"The stock filter has a female thread on one side and male
on the other. The filtering direction goes from male to female, with female to male
working as a cleaning cycle."* And, correcting a first telling of it: *"the fitting
I have is female to 3/8 barb, it should be in the BOM I sent earlier."*

It is: **McMaster 5346K56 — 3/8" hose barb × 1/2 NPT female**, which this BOM carries
struck through, superseded by the Shurflo swivels. It is not superseded any more.

**Orientation first, because it does not depend on the fittings.** §4's argument is
that the filter **collects on the drain and is swept clean on the fill**, so that
"sand migrates forward one pot per cycle — pumice fines returning to pumice." Apply
that to each tee separately, because the dirty side is not the same side at both:

> **Green tee — MALE end faces the POT.** Dirty water enters at the wand on retract,
> so retract is male→female (collecting) and dispense is female→male (sweeping the
> debris back out toward the pot). Reversed, the drain would run in the cleaning
> direction and the pot's sand would pass straight through pump B into the tank.
>
> **Tank tee — MALE end faces the TANK.** *(This corrects an earlier reading of this
> finding, which said the male end faced the tee.)* The thing a strainer at the tank
> protects is **pump A**, and what threatens pump A is the tank's own settled
> sediment, drawn in on fill. So fill is male→female (collecting) and drain is
> female→male — pushing what it caught back into the tank, where it settles out
> again. Facing it the other way makes the tank the thing being protected, which
> nothing asked for, and sweeps the sediment toward pump A instead of away from it.

**Both strainers therefore present their FEMALE end to the tee**, and that is what
makes the fittings come out even. One part on each side, and they are parts that
already exist:

| | strainer MALE end | strainer FEMALE end (tee side) |
|---|---|---|
| **green tee** | **McMaster 5346K56** — FNPT × 3/8" barb. Owned. | barb × barb × **1/2"-14 MNPT** tee leg, screwed straight in. |
| **tank tee** | **SFFN1-1220-01** — FNPT × 1/2" barb. §2 bought a 5-pack; four are fitted, so the spare is already in the drawer. | the same tee, same leg. |

So the purchase is **two identical barb × barb × 1/2"-14 MNPT tees and nothing
else** — no adapters, no couplers, no second thread handedness, and no hose stub
between a strainer and a tee. That is a better outcome than this finding reached on
its first pass, when the owned fitting was taken to be male × barb.

**And it closes finding 13's loose end.** 13 noted that deleting the printed housing
leaves the 1/2" → 3/8" step at the probe with nowhere to live. It lives in the
5346K56: that fitting *is* the step, and it is on the green strainer's male end,
which is exactly where the branch is allowed to narrow (§5 — the probe is 3/8"
anyway, so the branch's narrowest element does not move).

⚠ **One caution, and it is the owner's own measurement.** The 5346K56 is the brass
fitting behind *"my fittings are quite hard to thread"* (§2). Brass male-tapered into
plastic is what was hard; here it is brass FEMALE onto the strainer's plastic male
thread, which is the gentler direction of the same mismatch but still not plastic on
plastic. Tape it and stop at hand-tight plus a little — the strainer body is the
cheap part, but it is also the part that cracks.

**What the decision changed, so nothing is half-changed:**

- `src/line_filter.py` — **deleted.** With it, `src.test_pieces.test_screen_slice`,
  the coupon that existed only to answer whether a 0.2 mm nozzle renders its 0.25 mm
  slots. A coupon for a part nobody prints invites someone to print it and conclude
  something. git has both.
- `src/build.py` — `line_filter_screen` is out of `printed_parts()`, with the reason
  in place of the part.
- `DESIGN_V2.md` §4 — retitled *"two bought strainers at the tees,
  self-backflushing"* and rewritten. The backflushing argument is unchanged, because
  it was never the thing that was wrong; what it now applies to is the stock part the
  owner actually tested. The four costs are named there, including the one that is a
  genuine loss — see below.
- `bom_consolidated.md` — §3 carries the two tees (finding 14); the 5346K56 is
  un-dropped and moved up to §3 as the 1/2" → 3/8" step; §7b lost the screen row and
  its two paragraphs; the filament figure fell 299 g → 294 g and `check_bom.py` is
  what noticed; the screen is recorded in *Dropped* with why it was a good part.
- **The cost that is a real loss, named rather than lumped:** §4's printed housing was
  deliberately **unopenable**, because a threaded joint on a suction line is an
  air-leak path and priming is this project's headline problem. Two strainers at the
  tees add **four** threaded joints on suction lines. Accepted — they are taped
  tapered pipe threads, not the twist-off cap the argument was aimed at, and the
  system re-primes every cycle by design — but if priming regresses, these are the
  first joints to suspect.
- Still open, and now geometric rather than a purchase: **finding 16**.

### 14 — the two tees have never been on the BOM

> ✅ **CLOSED 2026-10-05, and BOUGHT 2026-10-06.** 13 decided what the tee IS, so
> this could be fixed: `bom_consolidated.md` §3 carries **two tees, barb × barb ×
> 1/2" male NPT, 1/2" hose-ID barbs** — **U.S. Plastic 62128, $0.91 ea, ordered**.
> The absence was the finding; the purchase was just a purchase, and it is done.
> (First sourced to Avidity Science 1610-2845-011 at $1.80 and re-sourced on
> freight: UPS-only, $20 to ship $3.60 of fittings. Kept as the fallback.)

Found while sourcing 13, and it is older than 13: §1 has needed two tees since the
anti-parallel arrangement was chosen, `src/plumbing.py` models both of them
(`TANK_TEE` at x +73, `GREEN_TEE` at x −73) and `check_plumbing.py` routes six
hoses through them — and `bom_consolidated.md` has never listed either one. Not
struck through, not deferred, not open: absent. The CAD gates cannot catch it
because a tee is a bought fitting and they measure printed geometry.

It is cheap to fix and is deliberately **not** being fixed in the same breath as
13, because 13 decides what the tee IS — plain barb × barb × barb if the printed
filter stays, barb × barb × **1/2"-14 MNPT** if the strainers go in. The **size**
is no longer open: 1/2", by finding 15.

### 15 — §5 asked for 5/8" tubing that §2 of the BOM had already decided against

**RESOLVED**, and not by argument. DESIGN_V2 §5 was titled *"Tubing — 5/8"
everywhere except the probe"*; `bom_consolidated.md` §3 bought 1/2" and carried a
⚠ guessing that §5 was "probably right because it is the broader, later
statement". Neither traced to the owner, whose only size instruction was *"the
green line has to stay 3/8 but all the other lines can change"* — which pins the
probe and frees everything else.

What settled it is that **§2 had already chosen, with reasons, and §5 never
noticed**: the pump-port fitting is SEAFLO SFFN1-1220-01, 1/2"-14 FNPT × **1/2"
barb**, and the owner has now bought five of them. A 5/8" tube does not grip a
1/2" barb. The main run is 1/2".

Two things fall out that were not written down anywhere:

- **§5's headline claim was backwards.** It justified 5/8" as *"one reducer
  instead of four"*. With 1/2" barb swivels on both ports of both pumps, going
  5/8" needs a step at **all four** — it would have reinstated exactly the thing
  it claimed to remove.
- **The owned hose clamps would not have fitted.** McMaster 5574K13 is 1/2"–3/4"
  ID; 5/8" ID vinyl is commonly 7/8" OD, outside that range. The 5/8" line would
  have cost new clamps as well as new pump fittings.

The residual is real and is recorded in DESIGN_V2 §5 rather than buried: at
3.0 GPM, 1/2" runs **4.90 ft/s** against the 2–3 ft/s a suction line wants, where
5/8" would have made 3.14. Accepted because the runs are short, the suction is
flooded (§2), and the pump's own port bore is ~0.51" — so the ports are a 1/2"
restriction whatever the hose is. Friction goes as roughly d⁻⁴⋅⁷⁵, so the
3/8" → 1/2" step already won 3.9× of the 11.3× that 3/8" → 5/8" would have.

### 16 — the strainers have a LENGTH, and it has never been measured

Opened by 13 closing. While the filter was printed and unplaced, its size was
nobody's problem: `src/build.py` exported it, `components()` did not carry it, and
§4 gave it no position on purpose. Two bought strainers at the tees do have a
position — inline on each tee's third leg — and therefore a length that has to fit.

**What the model says is available**, from `src/plumbing.py`:

| leg | run | straight available |
|---|---|---|
| green tee → wand | `GREEN_TEE` (−73, 262, **84**) straight down to `GREEN_EXIT` (−73, 262, **−40**), no bends | **124 mm**, and it leaves the pack, so a strainer can also hang below it |
| tank tee → Uniseal | `TANK_TEE` (+73, 262, **84**) up to **z 234**, with one corner at the top at `BEND_R` = 50 | **≈100 mm** |

**What is not known is the 51S01's length.** It is a tape-measure job on a part that
is already in the drawer, which is why this is a finding and not a blocker. The tank
leg is the tight one at ≈100 mm, and it is tight in a way the green leg is not: the
green leg's strainer can hang outside the pack, the tank leg's is boxed in between the
tee and the Uniseal, and `UNISEAL_Z` is set by *"seal needs wall either side of the
bore"*, so it is not free to move up.

**This is a gate-shaped hole, not just an unknown.** `check_plumbing.py` routes six
hoses and measures clearances, and it has no concept of an inline fitting occupying
length on a run — so it will keep passing whatever the measurement turns out to be.
If the number comes back near 100 mm, the fix is to teach the checker about inline
fittings rather than to eyeball it; if it comes back at 60 or 70, the honest thing is
still to record the figure here so the next person does not re-derive it.

### 17 — the level sensor drives its output to the SUPPLY, and the board assumed otherwise

Found while sourcing a US link, which is the only reason it surfaced: nothing in this
repo reads a vendor page, so no gate here could have caught it.

**What the board assumes.** `elec/main.py` feeds J5's V+ from **VBAT behind F1** — the
pack, 15 to 20 V — and reads the output on **IO14** through **R23, a 10k pull-up to
3V3**. R23's comment says what that rests on:

> *"Level sensor: runs at VBAT and its output is OPEN-COLLECTOR, so this pull-up to
> 3V3 is what keeps 18 V out of the GPIO. Push-pull mode would destroy it."*

`CIRCUIT.md` §7 makes the same argument and calls it load-bearing. The argument is
sound. **The premise is false.**

**What the parts actually specify.** Two pages, read 2026-10-05:

| source | input voltage | output HIGH |
|---|---|---|
| Amazon B074PVF341, titled "XKC-Y25-**NPN** … DC **5-24V**" | its own spec table says **DC 5~12V** | **"InVCC"** |
| Trumsense, manufacturer page for the **-V** | **DC 5-24V** | **"5-24V"** |

Both say the HIGH level is the **supply rail**. So "NPN" on these modules does not mean
a bare open collector reaching the pin — there is an internal pull-up to Vcc, and R23
loses to it. **At 18 V of supply, IO14 sees 18 V.** That is the destructive case
CIRCUIT.md names, and it is the default behaviour of the whole family, not a
mis-configuration.

And the listing titled 5-24V contradicts itself in its own specification table at
5~12V — which would have been destroyed by this board's supply even if the output had
been safe. **Two independent disqualifications in one listing.** A second listing
(B0GZ257F8T, "XKC-Y25-NPN-24V") is $44.68 with zero reviews and a 2-to-3-week ship,
and is not worth the risk premium.

**THE FIX, and it is two components in the sensor lead.** An NPN inverter makes the
sensor look like exactly what the board was designed for:

    sensor yellow (OUT) ─├ 10k ──── B      (10k and the 2N3904 are both OWNED, §8)
                               NPN (MMBT3904 / 2N3904, both already on this BOM)
    J5 OUT ───────────────── C          E ──── GND

- **R23 is the collector pull-up**, used exactly as designed. The pin cannot exceed
  3V3 no matter what the sensor does, so this is immune to the variant question
  entirely — and to the next listing that contradicts itself.
- **Base drive is not marginal, and — BOTH PARTS ARE ALREADY OWNED.** §8 of the BOM
  bought a **2N3904** and **10 kΩ** resistors for the cat-bed project and they are
  ticked. Use the 10k rather than buying a 22k: Ib is 1.43 mA at 15 V and 1.93 mA
  at 20 V, so at hFE 100 the transistor can sink 143–193 mA against the **0.33 mA**
  R23 actually needs (3.3 V / 10k) — saturated by a factor of ~400 at the bottom of
  the pack. ⚠ **R23 IS 300k NOW, NOT 10k -- see finding 30**, which raised the
  pull-up to hold a fault clamp under IO14's absolute maximum. That only makes
  this inverter easier: the collector has to sink **11 uA** rather than 0.33 mA,
  so the saturation factor gains another order of magnitude, and the MMBT3904's
  own Vce(sat) at 11 uA is far below the 0.2 V that finding 30's low-level margin
  was computed against. The two findings are consistent, and this line is
  corrected rather than left to read as 10k.
  The draw on the sensor's own output is 1.4–1.9 mA against its rated
  1–100 mA, so nothing is stressed at either end. **This fix costs nothing and
  needs no order.** (22k also works, 65–88 mA of sink; there is just no reason to
  buy one.)
- **Then tie the sensor's black MODE wire to VBAT rather than to J5's MODE
  terminal**, and the inversion cancels: MODE high → yellow goes HIGH when liquid is
  sensed → the NPN pulls IO14 LOW when liquid is sensed → which is exactly what
  `LEVEL_FULL_IS_LOW` already encodes. **No firmware change, no board change, no
  re-order.** J5's MODE terminal is left empty; it is only tied to GND on the board
  and nothing needs it.

**So what to buy is now simple, and it is the part the BOM originally named.** The
**-V** is the variant rated **5–24 V**, which is the only spec that still matters once
the inverter is in the lead — ironically the "NPN"-titled listing is the 5–12 V one.
Confirm 5–24 V **in the spec table, not the title**, and ignore the output type.

⚠ **The connector gets cut off, so the WIRE COLOURS become the only identification.**
The owner is cutting the supplied pigtail to get the cable length right (2026-10-05),
which is correct for a sealed run — but it also throws away the one thing that made
the pinout self-evident. From the manufacturer page: **brown = VCC, blue = GND,
yellow = OUT, black = M (mode)**. Verify with a meter on the part in hand before
trusting a colour, because these are re-sold by many houses.

⚠ **`CIRCUIT.md` §7 said "JST-PH to the XKC-Y25" and that was never what this board
has.** J5 is a 4-way 5.08 mm screw terminal, like the other four. Corrected.

### 18 — the tees neck the line to 9.27 mm, and §5 is the section that cares

Opened by reading the drawing for the tee bought in finding 14, which is the only
reason it is a number rather than a shrug. Thogus drawing **TT3888**, variant
**/P** (polyethylene — U.S. Plastic 62128):

| | inches | mm | |
|---|---|---|---|
| barb crest OD | 0.610 | 15.49 | 1/2" vinyl is 12.70 ID, so it stretches on properly — this is a real hose barb |
| **bore** | **0.365** | **9.27** | **53 % of the hose's area** |
| thread | — | — | MALE 1/2"-14 NPT, confirmed on the drawing itself |

**§5 of DESIGN_V2 exists to stop exactly this**, so it gets measured rather than
accepted quietly. At 3.0 GPM the throat runs **9.2 ft/s** against the hose's 4.9, and
as a contraction-plus-expansion pair (K ≈ 0.45 on the throat's velocity head):

> **0.26 psi per tee. 0.51 psi — 1.19 ft of head — over the two tees every flow path
> crosses.**

**Accepted, and here is the honest reason.** Against a 55 psi pump 0.5 psi is
nothing, but this project's headline problem is priming, not pressure, and 1.19 ft of
extra *suction* lift is the number that could have mattered. It does not, because §2
puts the tank **above** the pumps, so the suction is flooded rather than lifted — the
tees spend head the geometry already gives away for free. And it is unavoidable in
kind: every barbed fitting bores smaller than its hose, the owned SFFN1-1220-01
swivels included, and the pumps' own ports are ~0.51". A 9.27 mm throat 20 mm long is
a minor loss, not a line size.

**What would make it matter**, written down so the trade is not re-derived: moving the
tank below the pumps, or adding the check valve finding 12 deliberately omitted —
either turns a flooded suction into a lifted one, and then 1.19 ft comes out of a
budget instead of out of slack.

⚠ **Not the same as the trap it looks like.** `U.S. Plastic 37861`, which I briefly
recommended for the Uniseal's hose end, is a *poly-pipe insert*: barb 0.406" ID ×
**0.665" OD**, sized for ≈0.600" ID poly pipe, so its crest is ~2.8 mm oversize on
1/2" vinyl and it would not go on. 62128 is a hose-barb fitting and 37861 is a
pipe-insert fitting; the catalogue calls both of them "1/2 inch".

### 19 — the Uniseal's fitting stack overruns the hose's bend by ~29 mm

Finding 16 said the gate has no concept of an inline fitting occupying length on a
run, and named the two tee legs. **This is the same hole at the other end of the same
hose, and here it is not close.** It surfaced only because the owner wrote the
assembly out in order — Uniseal, PVC, PVC-to-FNPT, MNPT-to-barb, hose — which is a
stack of four rigid things before the hose starts, and nothing had added them up.

**The run, from `src/plumbing.py`:** `tank_down` leaves the Uniseal at
(73, **173**, 234), turns at (73, **262**, 234) and drops to `TANK_TEE` at
(73, 262, 84). So the horizontal leg is **89 mm**, and `BEND_R` is **50**, which this
module's own docstring says it needs *"on BOTH sides of the corner"*. That leaves
**39 mm** for everything rigid.

**The stack, outward from the tank wall:**

| | mm | source |
|---|---|---|
| PVC stub proud of the wall | ~25 | estimate — has to seat in the adapter socket |
| 1/2" PVC female adapter, net of the socket | ~13 | **estimate** — not yet a part number |
| 62017 beyond the FNPT face | 29.9 | **measured**: Thogus TA1088/P overall 1.69", ~13 mm of thread engaged |
| **barb tip off the wall** | **~68** | |

89 − 68 = **21 mm of hose before the corner centre, against the 50 mm the bend needs.
Short by 29 mm.** Two of the three figures are estimates, so the number is ±10 mm —
but the shortfall is three times that, and the one measured figure is the biggest.

**THE FIX IS A DIFFERENT FITTING, NOT A LONGER PACK.** Swap the straight 62017 for an
elbow (**62043**, Thogus TE2088/P) and the line turns down *at* the tank, which puts
the rigid stack on the leg that has room:

| | available | needs | |
|---|---|---|---|
| vertical drop, z 234 → 84 | **150 mm** | 100 (50 either side of one bend) | **fits, 50 spare** |
| horizontal at the bottom, y 211 → 262 | **51 mm** | 50 | fits, and only just |

So the elbow converts a 29 mm shortfall on the tight axis into 1 mm of slack on the
roomy one. That second row is tight enough to be the next thing that bites, and it is
the honest reason this finding is not closed by buying a part.

**What is actually still owed:** `src/plumbing.py` routes `tank_down` as a bare
centreline and `check_plumbing.py` measures hose against hose. Neither knows a fitting
has length, so **both will keep passing either layout**. Teaching the model about
inline fittings is the fix for 16 and 19 together — one list of (position, length)
along a run, checked against the straight each bend needs. Until then these two
findings are the only record that the model is optimistic at six places: two tee legs,
the Uniseal, and the three joints in between.

⚠ **Buy both 62017 and 62043.** $1.30 for the pair, against a freight charge many
times that for whichever one the assembly turns out to want.

### 20 — the level sensor's lead is 500 mm and the run is about 700

The owner, picking the part: *"It comes with a connector but I just assume cut it and
use our screw terminals so we can get the cable length right."* Cutting the connector
is right. **The assumption underneath it is backwards** — this lead is not long
enough to shorten.

**The listing is explicit**: EC Buying XKC-Y25-V, *"Line length: 500mm (± 10mm)"*.

**The run, from the model.** The Scepter stands on the lumber deck at `DECK_Z` 208
and `TANK_H` is 478, so its rim is at **z 686**. A *tank-full* sensor sits near that
rim — call it 30 mm down, **z 656**. J5 is in the PCB bay at `PCB_Z_C` **74.75**.

| | mm |
|---|---|
| vertical, sensor to J5 | **581** |
| `CIRCUIT.md` §7 routes it *"out the chase and then up the OUTSIDE of the case"*, so add the dip through the chase and the reach to the tank face | ~120, loose |
| **needed** | **~700** |
| supplied | **500** |
| | **short by ~200** |

Even putting the sensor at mid-tank height (z ≈ 450) gives ~495 mm needed against 500
supplied, so it is marginal at *every* plausible sensor height and short at the
realistic one. The 30 mm figure is an assumption; the shortfall is not sensitive to it.

**So the joint count goes up by one on the one lead that is already the most exposed
thing in the machine.** `elec/main.py`'s own comment on F1 says it: this lead *"leaves
the sealed bay through the chase and then climbs the OUTSIDE of the case to the tank
— so it is the one wire that gets rubbed, pinched and walked past."* A splice there
is not a detail.

**What to do, in order:**

1. **Solder it and seal it properly** — adhesive-lined heatshrink per conductor, then
   one outer sleeve, sited where it is clamped rather than mid-span. Not a crimp butt
   connector, and not a Wago on the outside of a pack that lives in the weather.
2. **Or buy a 1 m variant.** Several XKC-Y25 listings offer a "1M" lead option in the
   dropdown. Worth checking before clicking buy — it removes the splice for the same
   money, and the splice is the only thing this finding is really about.
3. **F1 is the reason this is a finding and not an alarm.** The sensor feed is behind
   a resettable PTC precisely because this lead is the one that chafes, so a splice
   that eventually shorts trips F1 rather than the pack. The protection already
   anticipated a fault on this wire; this finding just notes we are now adding one
   more place for it to start.

### 21 — CLOSED: all five terminals are on the −Y edge, and the board still passes everything

*(Raised as "J5 is on the WRONG EDGE of the board, against a requirement stated in
words". It was. The requirement, from the owner, verbatim and never withdrawn:)*

> *"Avoid moving the wiring connections to other sides of the board since it'll be
> convenient to have them all in the same side facing down."*

**Found while starting the wiring model the owner asked for**, which is the point of
drawing cables: you cannot route one without asking where it leaves from. J5 sat on
the **+Y** edge — world z 120.0 against the other four at 28.0 — so a four-conductor
cable had to climb 92 mm down the face of the board inside the sealed bay to reach the
only exit. Not a plan-view problem: 92 mm of **height**.

**Two documents said otherwise and both were wrong,** and the code already knew.
`src/housing.py` said *"the level sensor's lead leaves through this chase too"* and
`CIRCUIT.md` §7 said the same, while `_edge_connector_span()` **filtered J5 out**
(`if y0 > -PCB_L / 4.0: continue`, commented *"not on the bottom border"*). The chase
was sized from four terminals while the prose claimed five. **Both now agree with the
board**: the span measures 106.922…194.582 and J5 is in it.

**No gate caught it, and that is the finding behind the finding.**
`elec/cad_geom_check.py` checks the routed board against the CAD, `check_overlaps.py`
weighs solids, the quality pass reads the board. **An internal cable that no model
draws is in none of them.**

#### What it actually took

Not a re-space. The terminal **order** had to change, and that was the blocker the
working notes stopped on: J1 is the pack inlet and the only VBAT_RAW terminal, and
sitting it between the two pump terminals put a higher-priority VBAT_RAW stub
(x −14.65…−8.45) exactly across **VBAT's riser A** (x −12.0…−9.7), the path both
pumps' VBAT must take to D2's cathode tab. Both alternatives were shut — 0.61 mm to
PUMP_A_LO's column on the left, 0.36 mm to Q2's courtyard on the right — and the tab
could not be fed from the left either, PUMP_A_LO's bar being across that approach.

Final order **J5, J2, J3, J1, J4**: the two pump terminals adjacent so one VBAT bus
serves both, and the pack and its fuse beyond them. Courtyards, 0.5 mm gaps:

| | courtyard mm | placement x |
|---|---|---|
| J5 level (4-way) | 21.41 | −36.30 |
| J2 pump A | 11.26 | −19.50 |
| J3 pump B | 11.26 | −7.75 |
| J1 pack | 11.26 | +4.00 |
| J4 joystick (5-way) | 26.49 | +28.40 |
| **sum** | **81.68** into 91.00 usable | |

**VBAT cannot reach C1 along the bottom, and the first plan was wrong.** A column at
x −38…−35.5 rising from the bus would have to cross the pad band at y −48.3…−45.7,
where J5.2's pad occupies x −40.14…−37.54. The gap between J5.2 and J5.3 is 2.48 mm,
**1.68 after clearance, against the 3.18 mm IPC-2221 wants at 7.5 A.** So VBAT rises
**right of J5** instead, in the 6.84 mm between J5.4's GND pad (−27.38) and J2.2's
PUMP_A_LO pad (−18.46) — J2.1 being VBAT, the riser may land on its own net's pad
rather than clear it.

Every edge is a measured clearance, not a round number:

| edge | against | clear |
|---|---|---|
| bus top **−48.8** | J5's pads (−48.3) and J1.1's | 0.50 |
| bus bottom **−54.0** | the board outline | 2.00 |
| riser right of J5 **−20.74** | J5.4's GND pad −27.38 / J2.2's −18.46 | in the 6.84 mm gap |
| PUMP_A_LO link top **−29.3** | D2's tab pad bottom −28.90 | 0.40 |
| PUMP_A_LO bar right **−19.49** | D2's tab left edge −19.09 | 0.40 |
| PUMP_A_LO column right **−15.26** | VBAT_RAW's left edge −14.65 | 0.61 |
| VBAT riser B right **+14.60** | J4's courtyard +15.16 | 0.56 |
| VBAT riser B left **+8.10** | J1.2's GND pad +7.84 | 0.26 |

Bus height **5.2 mm** against the 3.18 IPC-2221 wants at 7.5 A.

#### ⚠ VBAT FILLED AS TWO ISLANDS, AND NO CLEARANCE ARITHMETIC WOULD HAVE CAUGHT IT

The left column was first drawn 2.5 mm wide (x −38.0…−35.5) to thread between D1's
pads. It passed every clearance check and **severed anyway**, because F1.1 — a pad on
**VBAT's own net** — sits inside it, and thermal relief around a same-net pad in a
2.5 mm channel leaves **0.13 mm a side**, below the fill's minimum width. Foreign-pad
clearance arithmetic cannot see this: the offending pad is not foreign. Widened to
**4.1 mm**, which also picks up D1.1 directly. Recorded because the next narrow pour
channel will look just as safe.

#### What moved, and what deliberately did not

Thirteen placements moved: J5 J2 J3 J1 J4 F2 C21 C17 C20 C16 F1 C18 R23. Two support
pads moved from y −50 to y −40 — a BOSS_D 10.4 boss at −50 lands on J5's new solder
tail at x −43.92 and J4's at +38.56.

**C1, C2, D1, Q1, Q2, D2 and D3 never moved.** Bulk capacitance stays at the switches,
the TVS stays at the entry. That was the owner's condition — *"so long as it doesn't
negatively impact the performance of the board"* — and it is the reason each pour
became an **L** (a column up from the terminal, a link below the diode's tab, then the
original bar on the tab and anodes) rather than a straight run.

#### The progression, because the middle of it is instructive

| step | unconnected | violations |
|---|---|---|
| first cut of the reorder | 8 | 2 (11 FAIL) |
| pours re-derived | 1 | 0 |
| VBAT column widened to 4.1 | 0 | 0 |
| R23 moved to the receiver | **4** | 0 |
| R23 reverted, A15 exempted | **0** | **0** |

**A better FAIL count was a worse board.** Moving R23 to the receiver cleared the A15
return-slot finding honestly — a pull-up on an open-collector line does belong at the
receiver — and cost 4 unconnected, because the router then took an F.Cu diagonal for
LEVEL across the power section and severed PUMP_A_LO and VBAT. Reverted, and the
remaining finding is accepted as **25** below rather than bought with routing damage.

**Closed at 0 unconnected / 0 violations / 0 FAIL / 0 OPEN**, 70 placements, 34 BOM
lines, 17 frames corrected and 0 unfitted. The board did not grow: still 95 × 112.

---

### 25 — ACCEPTED: ESP_RX_FROM_PROG crosses a 7.17 mm return slot, against a 5.00 limit

**A15 measures the widest ground-return gap any signal crosses.** One net fails:
`ESP_RX_FROM_PROG` at **7.17 mm against the 5.00 limit**, cut at board
(+27.66, +29.97).

**What forms the slot:** the MCU's fan-out bundle on the +Y side — PWM_A, PWM_B,
BUZZ, IO0, a 1.00 mm +3V3 trace and LEVEL — running side by side between U2 and the
board edge. LEVEL is in that bundle *because* J5 moved to the −Y edge, so this finding
is a direct cost of closing 21 and is recorded as one.

**All four corridor lanes were tried and none is routable.** `notes["corridors"]` lays
a 5-segment Manhattan pre-route across a barrier; the lane at **y −44.0 was placeable
and broke the board** — 10 unconnected, 3 violations — because that band carries
VBAT's leftward run. The other three had no room. All four are written into
`elec/main.py` beside the exemption so the next attempt does not repeat them.

*(Two process notes, because both cost time. `notes["corridors"]` is only read inside
the `local_nets` block — a board that defines no local nets accepts the key, ignores
it, and says nothing. And the corridor is laid during `finish.py`, not `main.py`, so
the confirmation line is not where you first look. I briefly credited the corridor
with a 0-unconnected result that actually came from removing the R9/TP2 stub.)*

**Why it is acceptable, named and measured rather than lumped:** `ESP_RX_FROM_PROG` is
J6's UART **receive** line, 115200 baud, live **solely while a USB-serial adapter is
plugged into the programming header**. It carries no signal at all in operation — the
machine runs with J6 empty. A return-path discontinuity costs edge-rate fidelity and
radiated emissions; at 115200 baud on a bench, with the board in a hand rather than on
a backpack, neither is a failure mode. **Every operational net passes**: the widest an
operating signal crosses is 3.02 mm, by JOY_FILT.

**The exemption has been made to fail — six ways.** It is net-scoped
(`return_slot_ok`), and `a15fail.py` runs the real A15 rule against the real routed
board with only that dict varied:

| case | result |
|---|---|
| as shipped, ESP_RX_FROM_PROG exempted | passes; widest 3.02 mm by JOY_FILT, 13 crossings |
| no exemption at all | **the 7.17 mm finding returns** |
| exempt an operational net instead (PWM_A) | ESP_RX still fails |
| exempt LEVEL instead — the net J5's move put in the bundle | ESP_RX still fails |
| exempt a net that does not exist | ESP_RX still fails |
| exempt **everything** | passes differently — widest 2.56 mm by +3V3 |

An exemption that would also swallow an operational net is not an exemption, it is a
disabled gate. This one names one net and **cannot cover for another**.

---

### 26 — CLOSED: moving J5 ate the board's Z retention, and the CAD gate caught it

**Found by `py -3.12 -m src.build` refusing to run** immediately after 21 landed:

> *a Z stop is only 2.3 mm long (min 4.0): the cable chase at 104.9..196.6 has eaten
> the floor it needs*

The cable chase is **derived from the routed terminals**, which is what makes it
correct and what made this bite. With five terminals on that edge the group spans
106.922…194.582 — 87.66 mm of the laminate's 95.0 — and with `CHASE_MARGIN` either
side the chase becomes **104.922…196.582: 91.7 mm, running 1.01 mm PAST the
laminate's +Y edge**, because J5's own outline ends 0.99 mm short of the board edge.
The two Z-stop bands derived from it came out **2.35 mm and inverted** (197.58, 194.57
— a negative length).

**Lowering the 4.0 mm minimum was the wrong answer, and the measurement says why.**
The chase exclusion was never protecting the ribs from the chase **cut**: the chase
removes the bottom wall over z 13.35…15.75, the −Z rib lives at z **16.05…18.45**,
and they clear by `RET_STOP_CLR`. The ribs were never in it.

**What was in the cable's way is the rib's OVERHANG.** It reached to
`BOARD_X1 - RET_STOP_OVER` = **−201.2**, which is 2.4 mm outboard of the laminate's own
face at **−198.8** — out in the space the terminal bodies and their cables occupy. A
rib crossing the chase with that overhang would stand in the descent path of the very
wires the chase exists for.

**The fix is an invariant, not a clearance guess.** The −Z rib now stops **at** the
laminate's outboard face: every connector body and every cable is outboard of
`BOARD_X1`, every part of that rib is inboard of it, so the two cannot meet — and the
laminate's full 1.6 mm thickness is still spanned, which is all a stop has to do. The
2.4 mm of margin it gives up bought nothing the laminate's own thickness did not
already provide. The **+Z** rib sits 115 mm up in Z from the chase, where there is no
cable to obstruct, and keeps its overhang.

Both therefore run the laminate's full length. **The stop is now 93.0 mm — longer than
the two-band scheme ever achieved**, on a board whose bottom edge is now entirely
connectors, and it is one continuous rib per Z edge instead of four short ones.

**Made to fail five ways, each by its own assert:** the −Z rib given the +Z pair's
overhang; the −Z rib stopping 1 mm short of the laminate; the ribs sunk into the
chase's Z band (the assumption that was implicit before and is now checked); the band
shortened back to a bump; the band running off the end of the laminate. All five
caught, and the file imports clean afterwards.

Verified after: 10/10 `tools/check_*.py` pass, **0 unintended overlaps**, every shipped
part still prints without support, and `cad_geom_check` reports 59/59 routed parts
where the CAD draws them.

### 27 — OPEN: two documents describe strain relief that does not exist

`elec/CIRCUIT.md` §7 says `src/housing.py` "puts a buttress rib on the back plate
under the board's bottom edge with a 10 × 7 mm tie slot through it (TIE_*)", and the
**signed quality item M38** repeats it: *"Strain relief is deliberately NOT at the
terminals ... which is why it is at the housing's buttress rib and its 10 × 7 mm tie
slot."*

**TIE_ appears 0 times in `src/housing.py`.** That file says so in its own words: the
ribs are *"gone at the user's request and nothing replaced them."* Same class as the
four-mounting-holes prose — a sign-off citing geometry that is not there.

Two more stale numbers in the same paragraph: the chase is given as **y 134..158,
"between J3 and J4"**. It is **104.9..196.6** and spans the whole row, because it is
derived from five terminals now, not four.

**The engineering gap underneath is real, and finding 21 made it bigger.**
`housing.py` names it: the wire slot is genuine relief for the battery pair, which
turns 90° against a close-fitting hole, but *"it is not relief for the leads that
arrive down the chase from the tank side (the level sensor, the joystick)"*. J5's
four-conductor lead is now on that same edge, so **three** unrelieved cables land
straight on a screw clamp, not two.

### 28 — CLOSED: lead_exit() refuses the question it was answering wrongly

`cadkit.board_geom.Boards.lead_exit()` is documented as *"the point a cable should be
drawn from"*. For J1–J5 it returned a point **15.67 mm off the board's FACE, pointing at
the lid** — the top-entry answer — when every one of those mouths faces **world −Z**, 6.65
mm above the chase.

**The cause was a 7-character prefix lookup.** `lead_exit` sees `Horizontal` in the fpid
and enters its side-entry branch, then keys `side_plug_run` on `name[:7]`, which for
`TerminalBlock_Phoenix_MKDS-3-...` is the string **"Termina"**. Nothing registers that
key, the lookup returned `None`, and the function **fell back to the top-entry formula
without a word**. Built on it, five cables would have been drawn leaving perpendicular to
the board, missing the chase entirely, and the model would have **passed** — a wrong
direction is still a valid point, so nothing downstream can tell it from a right one.

**Fixed in canonical cadkit** (`e8ebc68`), two changes:

1. **A side-entry part with no registered plug run RAISES.** The message names the fpid,
   says every prefix it tried, and tells the caller either to register the mated plug's
   run or — if the direction is a convention rather than a measurement — to declare it in
   the caller and say why there. *A helper that guesses the wrong direction in silence is
   worse than one that refuses.*
2. **The lookup is the longest registered PREFIX, not `name[:7]`.** Both keys in
   `SIDE_PLUG_RUN` happen to be exactly seven characters, so the slice worked by
   coincidence and would silently miss a key of any other length.

**Made to fail, and made to stay out of the way** — all five terminals refuse; `JST_PH_`
and `JST_XH_` are still registered; the one top-entry `J*` on the board is untouched; and
a run registered under a **25-character** prefix now *resolves*, which `name[:7]` could
never do. That last case then raises `_side_mouth`'s own refusal — *"the footprint origin
sits mid-body, so which end is the mouth cannot be read from the geometry"* — which is
exactly what finding 28 predicted from CIRCUIT.md §7's indeterminate 5.35 vs 5.95 mm. **The
two refusals agree**, and neither of them guesses.

`src/wiring.py` still **declares** the entry face (`ENTRY_FACE = "board -Y"`) with the
+Y-up/+Y-down reasoning, which is the right answer for a convention, and asserts the one
thing a convention can be held to: every mouth over the chase and within 20 mm of it.

### 29 — CLOSED: the pack pair fits; the model was drawing it gathered through a slot that is one layer deep

**The wiring model's first real catch, and what it caught was the MODEL.** With the
harness in `components()`, `check_overlaps.py` reported **15.1 mm³ wire_pack ↔
housing** at x −193.2..−190.0, **z 4.70..11.30** — the back plate at the wire slot,
which is **5.00 mm tall (z 5.50..10.50)**. A gathered 2 × 14 AWG bundle is **6.60 mm**
and does not fit.

**But the harness does fit, and `src/wiring.py`'s own comment had already said why
before the gate was run:** the slot is **one layer deep**, so the conductors cross it
**side by side**, not gathered. Two 3.30 mm conductors lying flat are **3.30 tall and
6.60 wide** — which is exactly what the slot was sized for, and what finding 3's
17.8 mm side-by-side arithmetic assumed all along. The gathered diameter is still the
right model for the four runs that do **not** cross the plate, where a cable really is
gathered.

**Fixed by drawing the cable as it lies.** `LAID_FLAT` names the cables that cross the
slot — only the pack pair does — and those are emitted as one solid per conductor,
each bending on its own radius. Two new asserts hold it: a laid-flat conductor must be
no taller than the slot, and its conductors laid side by side no wider. **That is the
check whose absence let a 6.60 mm round bundle be drawn through a 5.00 mm slot.**

**Result: the harness is now IN the overlap gate** — 23 components weighed,
**0 unintended overlaps** — so from here a cable is checked against the housing, the
lid, the board and every other cable by the same gate as everything else. The
2.0 mm³ `wire_pack ↔ pcb` reading at the mouth resolved itself in the same change:
with per-conductor lanes the wires straddle the clamp instead of sitting dead-centre
in its body, so no `intended()` entry was needed after all.

#### ⚠ AND THE RIB HALF OF THIS FINDING WAS MINE, AND IT WAS WRONG

This finding was first written claiming that finding 26's now-continuous −Z stop
crosses the wire slot's Y span and blocks the pack pair, and that **finding 26 had
overclaimed its invariant**. **Both claims are withdrawn.** The geometry does not
support them and the measurement never did:

* The reported clash was at **x −193.2..−190.0 — the plate**. The rib lives at
  **x −193.2..−198.8**. Different region; the gate never pointed at the rib.
* The turn's arc centre is at **(x −197.53, z 17.9)**, so where the cable crosses the
  rib's x band it is at **z ≈ 8.08**, not 17.9. It only reaches the rib's height at
  **x −207.43**, which is 8.6 mm outboard of the rib's outer edge. The arc leans
  *away* from the board, not across it.
* So the 6.4 mm "band between the slot and the rib's underside" that this finding did
  its arithmetic in **is not a band the cable ever occupies.**

**Finding 26's invariant stands as written** — every connector body and every cable is
outboard of `BOARD_X1` where the rib is inboard of it — and the pack pair does not
violate it, because it drops to slot height *before* it travels inboard rather than
after. The exception I inserted into finding 26 has been removed.

**The error was reasoning about a bend instead of measuring one**, after the gate had
already told me where the volume was. I put the arc's centre on the wrong side of the
corner, which puts the whole arc 9.9 mm too high. Recorded because it is the same
mistake as the render-read in finding 24, one level up: **the gate gave a coordinate
and I argued past it.**
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

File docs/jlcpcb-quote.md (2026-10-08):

# The main board's JLCPCB quote, measured (2026-10-06, re-quoted 2026-10-07, re-uploaded and CARTED 2026-10-08)

Asked for: upload the board, check that everything looks right, and keep the pricing
line items so savings have somewhere to be argued from. Method borrowed from the pedal
steel project, where a guessed cost model was wrong by 2x to 12x and the fix was to put
a real fab package through the real order form and read the answer.

Nothing was ordered. The quote auto-saves into the JLCPCB account under
**Projects > Quotes**, project name `main`.

## 2026-10-08: the whole package re-uploaded, and the board is IN THE CART

**Still nothing ordered.** It is saved in the cart, not paid for; the owner checks out.

This is the upload `ORDER.txt`'s BLOCKER demanded and it is now DISCHARGED: the
package that went up is the current `elec/out/fab/main.zip`, all sixteen files,
regenerated immediately before the upload (70 placements, 34 BOM lines, 0 OPEN).
The two silkscreen respins that happened after the 10-07 quote -- the face change
and the ink widening to the 0.15 mm fab floor -- are on the fab's server now. The
10-07 package is no longer the one being quoted against.

**The parts match was verified mechanically rather than read off the screen.** The
page said *34 parts detected, 34 parts confirmed*, which is the same sentence it said
on 10-06; so the 34 designator-sets and their matched LCSC codes were scraped off the
review table and diffed against `main-bom.csv`. **70 references, 34 lines, zero
mismatches, nothing matched that is not in our BOM and nothing in our BOM unmatched.**
The comparison was then fed a deliberately wrong code for U2 and it reported the
substitution, so the agreement is a measurement and not an empty loop.
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

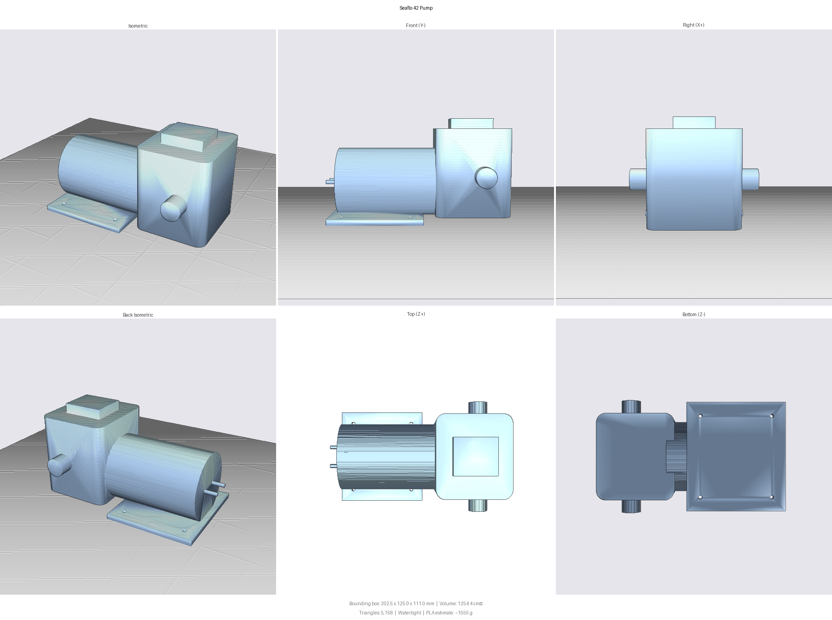
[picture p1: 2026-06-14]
references/seaflo_42_pump_preview.png

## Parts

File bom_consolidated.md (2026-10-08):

# Consolidated Parts List — by Vendor

Two projects on one buying run. Tags keep them separate:
- 🎒 = **Watering Backpack** — now at **v2** (see [DESIGN_V2.md](DESIGN_V2.md))
- 🐱 = **Cat Bed Weight Sensor**

**v2 changed the architecture substantially.** The 4-way reversing valve is gone
(replaced by a second pump), the 12 V rail is gone (pumps run from the battery through
on-board MOSFETs), and the tubing is up-sized from 3/8" to 1/2". **The frame is now
lumber rather than printed** (§7), which leaves exactly one printed assembly: the
battery mount and PCB case (§7b). Parts that v1 bought
and v2 no longer uses are listed at the bottom rather than deleted — several were
bought and are on the shelf, and the reasoning is worth keeping.

---

## 1. Seaflo  *(🎒)*

- [x] 🎒 **Seaflo 42-Series pump — SFDP1-030-055-42 — BOTH BOUGHT.** One carried
  over from v1; the second bought for v2 (owner, 2026-10-05), $64.99–$78.99 — https://seaflodirect.com/seaflo-42-series-diaphragm-water-pressure-pump-3-0-gpm-55-psi-choose-12v-or-24v/
  - ⚠️ **Select 12V** in the Voltage dropdown (not 24V).
  - v2 runs **two pumps in anti-parallel** — one plumbed tank→pot, one pot→tank —
    instead of reversing flow through a valve. A diaphragm pump cannot be reversed
    (its check valves are passive). ⚠ This line used to carry on "and those same
    check valves seal the idle pump's branch, which is what makes this work" — that
    is true of a STOPPED system and not of the one this builds: anti-parallel presents
    the idle pump with a FORWARD differential, which its check valves pass. Built
    without a check valve deliberately; DESIGN_V2 §1 and WORK_V2_PUNCHLIST finding 12.
  - Ports are **1/2"-14 MNPT** (confirmed against Seaflo/West Marine listings).
  - ⚠️ **Bypass the internal pressure switch** on both — it cuts the pump on downstream
    pressure, fighting PWM.
  - 📦 Each pump includes a 50-mesh inlet strainer and 2× 1/2" barb adapters
    (straight; v2 uses 90° swivels instead). **Two pumps therefore put exactly two
    strainers on the shelf, which is the number §4 needs** — no spare, so neither
    is expendable. Four straight adapters come with them and go unused. ⚠ **Do not discard the strainers.** They were written
    off here as "redundant — v2 filters on the green line", and one of them has since
    been backflushed and cleared itself, which is the whole argument §4 makes for the
    printed screen. ✅ **DECIDED 2026-10-05 — they go at the two tees and the printed
    screen is not built** (WORK_V2_PUNCHLIST finding 13, closed). ⚠ **They are DIRECTIONAL**:
    they filter male→female and clean female→male (owner, measured), so the male
    end faces what each one protects against — the **pot** on the green tee, the
    **tank** on the tank tee. Both therefore show their female end to the tee.
    Fitted backwards a strainer sweeps its debris toward the pump instead of away
    from it. Finding 13a.

## 2. Seaflo — pump fittings  *(🎒, NEW in v2)*

- [x] 🎒 **SEAFLO SFFN1-1220-01 — 1/2"-14 FNPT × 1/2" barb, 90° swivel elbow — 5-pack, $12.99 — BOUGHT**
  - https://seaflodirect.com/seaflo-plastic-pex-pipe-coupling-90-degree-fitting-swivel-adapter-1-2-14-fnpt-x-1-2-barb-elbow-fitting-compatible-with-pex-or-pe-rt-pipe-cor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
  - SKU `SFFN1-1220-01-5`. Material **PA66 nylon**, potable-water rated. The 5-pack is
    exactly the quantity wanted: 4 fitted (2 per pump) + 1 spare for the fit test.
  - **Why this part, three reasons:**
    1. **Swivel** — the elbow is aimed *after* tightening. NPT is tapered, so a fixed
       elbow lands wherever it seals; a swivel removes that constraint entirely and
       lets the pump bay be packaged tight. The CAD depends on this: it models one
       clearance envelope per port with the leg aimed by `PORT_CLOCK`, which is only
       legitimate because the clock angle is chosen, not inherited from the taper.
       Three of the four aim out the front; pump B's inner leg aims UP, because
       forward is pump A.
    2. **Nylon, not brass.** The pump head is moulded plastic; a brass female fitting
       bites and is how you crack a port by over-tightening. This is the answer to
       *"the filter that comes with the pump screws on easily but my fittings are quite
       hard to thread"* — the strainer is plastic on plastic and these are too.
    3. **Seals on an O-ring, not the thread taper** (no PTFE needed). A marginal taper
       seal on the suction side draws air, a standing suspect in v1's priming failures.
       It is also *why* it threads easily: the thread only holds the joint closed, so
       there is no torque-to-seal to get wrong.
  - **This replaces Shurflo 244-3926, and the swap removes the open risk.** The Shurflo
    part was a *Pentair* fitting hoped to fit a *Seaflo* pump, and the BOM had to carry
    "fit is likely but UNVERIFIED — buy one and test before relying on four", because
    nothing established that Seaflo replicated the shoulder Shurflo's O-ring seals
    against. This is Seaflo's own fitting for Seaflo's own 1/2"-14 port, so that
    question does not arise. The Pentair page was also **not purchasable** — a
    "where to buy" landing page with no listing and no cart.
  - Still unmeasured: the fitting's **dimensions**. `ELBOW_NUT_D/L` and `ELBOW_LEG_D/L`
    in `src/pump_frame.py` remain conservative estimates, and the lumber frame's
    `POST_X` — hence how far apart the posts get cut — is derived from `ELBOW_NUT_L`.
    Measure one on arrival and re-run the build: the frame should get *narrower*, not
    wider, since the estimates were set for a brass fitting.
  - **Fallback if the swivel turns out to be clocked or the barb profile is wrong:**
    SEAFLO **51F03**, 1/2"-14 FNPT × 1/2" barb angled pump fitting, $5.49 (POM/PP),
    sold in 1/2/4/10 packs and listed explicitly for Shurflo/Seaflo/Jabsco pumps —
    https://seaflodirect.com/seaflo-no-51f03-1-2-14-fnpt-x-1-2-barb-angled-universal-pump-fittings-for-shurflo-seaflo-circle-river-johnson-jabsco-flojet-remco-lippert-us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
    Nothing in its listing calls it a swivel, so treat the clock angle as inherited
    from the taper if this one is used — which the frame is *not* currently drawn for.
  - Size: a 5/8" barb would add suction margin, but 1/2" is chosen because the port
    bore is ~13 mm regardless, v2's runs are short, and 1/2" vinyl bends to ~50 mm vs
    ~65 mm — real money in a 206 mm bay.

## 3. Tubing & plumbing  *(🎒)*

- [x] 🎒 **Two tees — U.S. Plastic item 62128, $0.91 ea — PURCHASED 2026-10-06** —
  https://www.usplastic.com/catalog/item.aspx?itemid=27820
  1/2" NPT × 1/2" hose ID × 1/2" hose ID, black HDPE, 125 psi with clamps,
  −65 to 190 °F. Qty **2**, one per tee, $1.82 the pair.
  - **The thread is MALE**, which is the whole point and the page title does not say
    so: the product family it sits in is *"Black HDPE Hose Barb x **Male** Threaded
    Tees"*. Plastic, so the male leg threads into the strainer's plastic FNPT without
    §2's brass-into-plastic problem.
  - ✅ **The barbs are specified for 1/2" HOSE ID**, which was the one thing that had
    to be checked before ordering: irrigation-aisle "1/2 inch" barbs are sized for
    0.600" ID poly and would have been ~2.5 mm oversize on 1/2" vinyl. Worth ten
    seconds with a caliper on arrival anyway.
  - *Rejected on freight, not on merit:* **Avidity Science 1610-2845-011**, $1.80 ea,
    the first pick and a good part — UPS only, $20 to ship $3.60 of fittings. Kept as
    the known-good alternative if 62128 ever goes out of stock —
    https://www.avidityscience.com/fitting-barbed-tee-adapter-1-2-barb-x-1-2-barb-x-1-2-male-pipe-thread-plastic-1610-2845-011
  - ❌ **DO NOT add item 37861** — I recommended it on the same order and it is the
    wrong part twice over. Its own page calls it *"a plastic insert for adapting
    polyethylene flexible pipe"*: the barb is **0.406" ID × 0.665" OD**, sized for
    1/2" POLY pipe (≈0.600" ID), so its crest is ~2.8 mm oversize on 1/2" vinyl.
    And it is **MNPT × barb with no slip socket**, so it cannot solvent-weld to the
    Uniseal's PVC stub, which was the entire job it was suggested for. §3's Uniseal
    entry carries the correct chain.
  - ⚠ **The barb BORE is a restriction, measured not waved at** — WORK_V2_PUNCHLIST
    finding 18. Thogus drawing TT3888: crest **0.610"** (15.49 mm, so 1/2" vinyl
    stretches on properly) but bore **0.365"** (9.27 mm), 53 % of the hose area.
    0.26 psi per tee, 0.51 psi over the two each path crosses. Accepted.
  - **Why this list needed them at all, recorded because nothing else catches it:**
    §1's anti-parallel arrangement has needed two tees since it was chosen,
    `src/plumbing.py` models both (`TANK_TEE` at x +73, `GREEN_TEE` at x −73) and
    `check_plumbing.py` routes six hoses through them — and this list had never
    carried either one. No CAD gate could catch it: a tee is a bought fitting and the
    gates measure printed geometry. WORK_V2_PUNCHLIST finding 14.
  - **The male leg is what the decision bought.** The owner chose the two bought
    Seaflo 51S01 strainers over the printed screen (WORK_V2_PUNCHLIST 13), and
    finding 13a shows both strainers face their **FNPT** end at the tee — so one
    male-threaded leg screws straight into each, with no adapter and no hose stub.
  - **Nothing else is needed.** The strainers' MNPT ends take parts already in the
    drawer: the **owned McMaster 5346K56** (FNPT × 3/8" barb) on the green side,
    which is also the 1/2" → 3/8" step at the probe, and a **spare
    SFFN1-1220-01** (FNPT × 1/2" barb) on the tank side.
  - ⚠ **One thing is still unmeasured, and it is geometric, not a purchase:** each
    strainer now sits inline on its tee's third leg, and nobody has measured the
    51S01's length. The model says the green leg has **124 mm** of straight (tee at
    z 84 down to the exit at z −40, and it leaves the pack, so it can also hang
    outside) and the tank leg has about **100 mm** (z 84 up to the Uniseal at
    z 234, less the 50 mm bend radius at the top). WORK_V2_PUNCHLIST finding 16.

- [ ] 🎒 **1/2" ID vinyl tubing — UPSIZE from 3/8"** (Ace ProLine or equivalent)
  - v1 ran 3/8" at **8.7 ft/s**; suction lines want 2–3 ft/s. 1/2" brings it to 4.9 ft/s
    and cuts friction ~3× (loss scales with v²). This is the single cheapest improvement
    to v1's priming margin.
  - **The green line stays 3/8"** where it enters the inner-pot tube — that diameter is
    fixed by the pot. Only the probe; the main run is 1/2". **The transition is the
    owned McMaster 5346K56** (1/2 NPT female × 3/8" barb), screwed onto the green
    strainer's MNPT end — it used to be the printed filter housing, which §4 no
    longer builds.
  - ✅ **RESOLVED 2026-10-05 — 1/2", and this line was right all along.** This
    carried a ⚠ UNRESOLVED against DESIGN_V2 §4/§5's "5/8 everywhere except the
    probe", guessing §5 was "probably right" because it was the broader, later
    statement. It was not settled by argument: **the owner has bought the pump-port
    fitting**, SFFN1-1220-01 with a **1/2" barb**, and a 5/8" tube does not grip a
    1/2" barb. So §2 of this list had already made the decision when it chose that
    fitting, and DESIGN_V2 §5 never noticed. Both are reconciled now, and
    the 1/2" figure is now the only one in the docs. *(`src/line_filter.py` used to
    carry this reconciliation; the module is retired — see §7b.)*
    - The residual is named in DESIGN_V2 §5 rather than buried here: 1/2" runs at
      **4.90 ft/s**, above the 2–3 ft/s a suction line wants, against 5/8"'s
      3.14. It is accepted because the runs are short, the suction is flooded, and
      the pump's own port bore is ~0.51" — so the ports are a 1/2" restriction
      whatever the hose is.
- [x] 🎒 **Hose clamps — 5574K13 — ALREADY OWNED, and now definitely correct** —
  McMaster, worm-drive, smooth-band, 304 SS, **1/2"–3/4" ID**. Centres on 1/2" ID
  vinyl's ~3/4" OD. ⚠ Worth recording that this was a near miss rather than a
  comfortable fit: 5/8" ID vinyl is commonly 7/8" OD, which is **outside** this
  range, so the 5/8" line the docs used to call for would have needed new clamps
  as well as new pump fittings. The 1/2" decision (§3 above) keeps a part that is
  already in the drawer.
- [x] 🎒 **Uniseal — 1/2" pipe size, $2.75 — PURCHASED 2026-10-06** —
  https://www.saltwateraquarium.com/uniseal-1-2-inch-pipe-pipe-grommets-pipe-to-tank-seals-uniseal/
  **1.25" hole saw**, seals on **0.840" OD = 1/2" schedule-40 PVC**, and the vendor
  says to *"insert the pipe… to clear the inside of the seal by about 1 inch."* So it
  grips rigid PIPE, not the hose — 1/2" ID vinyl is 0.750" OD and would be loose in it.
  **The chain from tank to hose.** The seal and both hose adapters are bought; what
  is left is the three Ace lines broken out as their own entry below, so a tick on
  this line means the seal and not the whole joint.
  1. short piece of **1/2" sch-40 PVC** — through the seal, ~1" proud inside the tank.
     Deburr and chamfer the cut end and wet it, or a square burr rolls the seal lip.
  2. **1/2" PVC FEMALE adapter, slip × FNPT**, solvent-welded to the stub outside
     the tank (primer + cement). ⚠ **FEMALE.** This step read "male adapter,
     slip × MNPT" for one revision while step 3 was also male — two male threads
     do not mate, and nothing in this repo checks a thread gender.
  3. **U.S. Plastic item 62017 — PURCHASED** — 1/2" MNPT × 1/2" Hose ID black HDPE
     adapter, Thogus **TA1088/P** — screwed into step 2, then the hose and one of
     the owned 5574K13 clamps.
     https://www.usplastic.com/catalog/item.aspx?itemid=27798
     **Put it on the tee order.** This is the step where the poly-pipe trap bites,
     and 62017 is the same Thogus hose-ID family as the tees with the same
     verified numbers off drawing TA1088: **MALE 1/2"-14 NPT** on the drawing,
     crest **0.600"** (15.2 mm, so 1/2" vinyl stretches on), bore **0.365"** —
     identical to the tee's, so it adds no restriction the line does not already
     have. Buying it here instead of off an Ace peg is the whole point: the
     catalogue that burned us on 37861 is the one we can now read drawings from.
  3b. **U.S. Plastic item 62043 — PURCHASED** — 1/2" MNPT × 1/2" Hose ID black
      HDPE ELBOW, $0.79 (Thogus TE2088/P) —
      https://www.usplastic.com/catalog/item.aspx?itemid=29593
      Not an alternative on style: **the straight stack does not fit the route**,
      measured in WORK_V2_PUNCHLIST finding 19 — it overruns the hose's bend by
      ~29 mm. The elbow turns the line down AT the tank, which moves the fittings
      onto the 150 mm vertical leg instead of the 89 mm horizontal one. Buy both:
      $1.30 for the pair against a second freight charge is not a decision worth
      making from a spreadsheet, and the parts in hand settle it in a minute.
      **Both bought 2026-10-06**; which one gets fitted is settled at the tank, and
      whichever loses costs $0.51 or $0.79 and stays in the drawer.
  *(This line used to read "size TBD once a Scepter panel is measured". The size never
  depended on the panel — it follows from the PVC stub's 0.840" OD. What the panel
  decides is only whether there is flat wall enough for a 1.25" hole.)*
  - For the tank's low outlet (flooded suction). The Scepter's 44 mm opening is too
    small to get a hand inside, so a conventional bulkhead — which needs a nut held on
    the inside — is impossible. A Uniseal installs **entirely from outside**: drill, work
    the seal in, push rigid pipe through. Standard on IBC totes and sealed barrels.
  - Fallback if it doesn't suit: keep the top-routed dip tube and add a **foot valve** at
    its bottom so the column can't drain back. Less robust (a weeping foot valve loses
    prime overnight) but needs no modification to the tank.
- [ ] 🎒 **Ace, for the Uniseal joint — three lines, none sourced by part number**
  because they are commodity plumbing and the aisle is the catalogue:
  - **1/2" schedule-40 PVC pipe**, a short piece. Deburr and chamfer the end that
    passes through the seal, and wet it — a square sawn burr rolls the seal lip.
  - **1/2" PVC FEMALE adapter, slip × FNPT.** ⚠ FEMALE — both hose adapters above
    are male, and nothing in this repo checks a thread gender.
  - **PVC primer + cement**, small cans.
  - *(and a **1-1/4" bi-metal hole saw** for the tank, if not already owned — the
    size is the Uniseal's, not a choice)*

- [ ] 🎒 **Check valve, 1/2" barb — for the pot (green) line** — holds the suction column
  between cycles. v2 ingests air at the end of *every* retract by design, so re-priming
  is routine, not exceptional.

- [x] 🎒 **McMaster 5346K56 barbed adapter** (3/8" hose × 1/2 NPT female) —
  **OWNED, and not superseded after all.** It is struck off in *Dropped* below as
  replaced by the Shurflo swivels, and for the pump ports it is. But the owner has
  it, and finding 13a gives it the job no other fitting here can do: it screws onto
  the green strainer's plastic MNPT end and *is* the 1/2" → 3/8" step at the probe
  that §5 needs and that the printed housing used to provide. ⚠ This is the brass
  fitting behind §2's *"my fittings are quite hard to thread"* — tape it, hand-tight
  plus a little; the strainer body is what cracks.

## 4. Sensing & UI  *(🎒)*

- [ ] 🎒 **XKC-Y25 non-contact capacitive liquid level sensor — qty 1.**
  ⚠ **THE VARIANT IS LOAD-BEARING AND THIS LINE USED TO NAME THE WRONG ONE.** It
  said "XKC-Y25-V (or similar)"; "or similar" is wrong three ways and -V may be wrong
  too. The board feeds this sensor from **VBAT behind F1 (15–21 V)** and reads it on
  **IO14 through the on-board inverter Q4** — R29 100k into the base, R30 100k holding
  it down, collector pulled up by the 300k string R23/R27/R28.
  ⚠ This line used to read **"R23, a 10k pull-up to 3V3"**, and claimed it "only keeps
  18 V off the pin if the output is a true NPN open collector". That was wrong twice:
  R23 is **100k and is not on that
  net**, and no pull-up of any value could do it, because the sensor drives its HIGH to
  InVCC and would win. What keeps the pack off IO14 is **R29 and Q4's b-e junction**.
  The variant still matters, for a different reason — the sensor has to survive and
  switch on an 18 V supply, and a PNP output would source the pack into R29 rather than
  sink Q4's base. So:
  - **5–24 V input.** Several listings are **5–12 V** sub-variants; 18 V kills those.
  - **NPN open-collector output.** Not PNP (sources the supply into the pin), not
    RS485 (no driver on this board), and **not necessarily -V**: the vendor describes
    the -V's HIGH output as "5-24V", i.e. supply-referenced — see
    WORK_V2_PUNCHLIST finding 17 before landing a wire on J5.
  - **4 wires preferred** (V+, GND, OUT, MODE). J5 is a 4-way and `elec/main.py`
    ties MODE to GND to select normally-closed, which is what the firmware's
    `LEVEL_FULL_IS_LOW` encodes. A 3-wire part fixes the polarity in the part number
    instead, and then the firmware constant has to match it.
  ✅ **BUY THIS ONE: EC Buying XKC-Y25-V, $9.59, ASIN B0C73F96MF** —
  https://www.amazon.com/dp/B0C73F96MF
  Chosen because its listing does not contradict itself, which is not a low bar
  here. Its spec block and Amazon's own attribute field BOTH say **DC 5-24V**, and
  5–24 V is the only spec that still matters once finding 17's inverter is in the
  lead. 4.6★ / 17, 50+ bought in the past month, Prime. The block also states
  *"Output voltage (high level): VIN"* in black and white, which is the
  confirmation finding 17 was built on rather than a contradiction of it.
  - ❌ **Rejected: Amazon B074PVF341** ("XKC-Y25-NPN … DC 5-24V"). Its own spec
    table says **DC 5~12V**, which this board's VBAT would destroy, and *also*
    "high level = InVCC". Two disqualifications in one listing. Finding 17.
  - ❌ **Rejected: Amazon B0GZ257F8T**, $44.68, zero reviews, 2–3 week ship.
  - ⚠ **ITS LEAD IS 500 mm AND THE RUN IS ABOUT 700** — WORK_V2_PUNCHLIST finding
    20. Plan on EXTENDING it with a soldered, adhesive-lined-heatshrink splice,
    not on cutting it to length.
  - Clamps to the **outside** of the tank wall; nothing penetrates the tank and nothing
    touches the water, which sidesteps the 44 mm opening entirely.
  - Power **directly from the battery rail** (5–24 V spec covers the pack's 15–21 V, with 3 V to spare at the top) —
    the v2 board only makes 3.3 V, so this matters.
  - Configure output **NPN open-collector**, pulled up to 3.3 V on the board. Push-pull
    mode would put 18 V into a GPIO.
  - **Mount it slightly BELOW the true full line.** A false positive is cheap (stop
    early, look); a false negative overflows. Capacitive thresholds drift with
    temperature, so bias toward tripping early.
- [x] 🎒 **KY-023 joystick — ALREADY OWNED, KEPT** — https://www.aliexpress.us/item/3256809150872159.html
  - Measured noise on battery is **sd 7–9 counts**, which is healthy. The ~120-count
    noise that cost a session to diagnose was a USB-tether artifact, not the wiper —
    there is no observed fault to justify a hall-effect replacement, and hall thumbsticks
    are consumer repair parts rather than distributor stock anyway.
  - Powered from **3.3 V, not 5 V**, so the output stays inside the ADC range.
  - Connects by a 5-pin cable to a terminal block on the main board. Only VRy is used; wire all
    five anyway (free, and leaves SW available as a mode button). The 2.54 mm housing
    doesn't latch, so **the printed mount must capture it** — that, not a new PCB, is
    the fix for v1's flying leads.

## 5. Power & protection  *(🎒)*

- [x] 🎒 **Makita 643852-2 terminal — qty 2 (one spare)**, $8.84 ea, ERP10153397 — https://www.ereplacementparts.com/parts/drill/makita/erp10153397/terminal-643852-2/
- ~~**Inline fuse holder — 8110K3**~~ — **NOT NEEDED, and no longer a checkbox** so
  it stops appearing in the to-buy list. The fuse moved onto the
  board as **F2** (Littelfuse 178.6165 FLR holder, LCSC C207061, on the PCBA BOM).
- [x] 🎒 **10 A blade fuse — 7460K45** — McMaster, ATC, 32 V, fast-acting, 5-pack, $3.83.
  **This is the fuse F2 holds.** The holder was chosen to suit it, so the blade itself
  is owned and never appears on the PCBA BOM.
- [x] 🎒 **M2×20 socket screws — OWNED** (McMaster 91292A013) · **M2 heat-set inserts —
  OWNED** (McMaster 94459A110, brass, 2.5 mm).
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

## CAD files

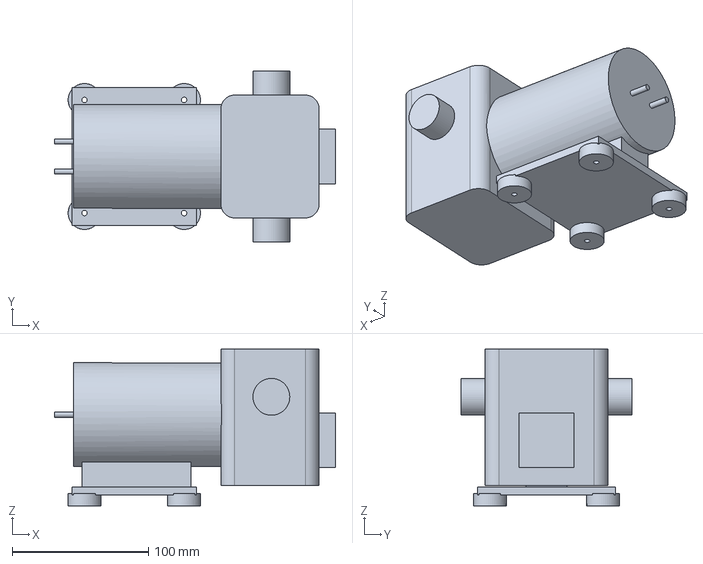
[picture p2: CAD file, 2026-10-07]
references/seaflo_42_pump.step
206.0 x 125.0 x 115.0 mm

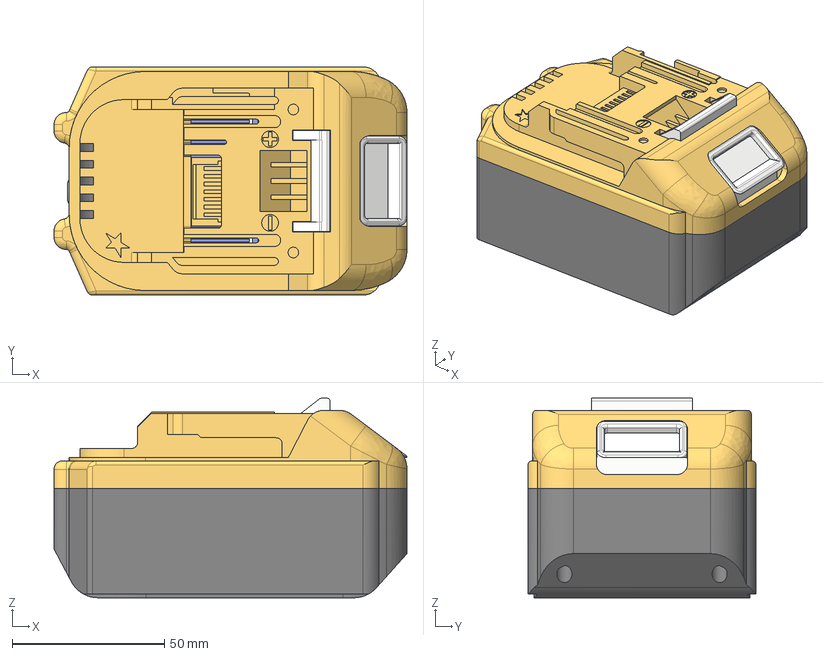
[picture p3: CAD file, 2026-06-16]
references/makita_battery.step
116.0 x 75.0 x 65.6 mm
Battery Plate
Battery Clip
Yellow Connector
Power Clips
Case

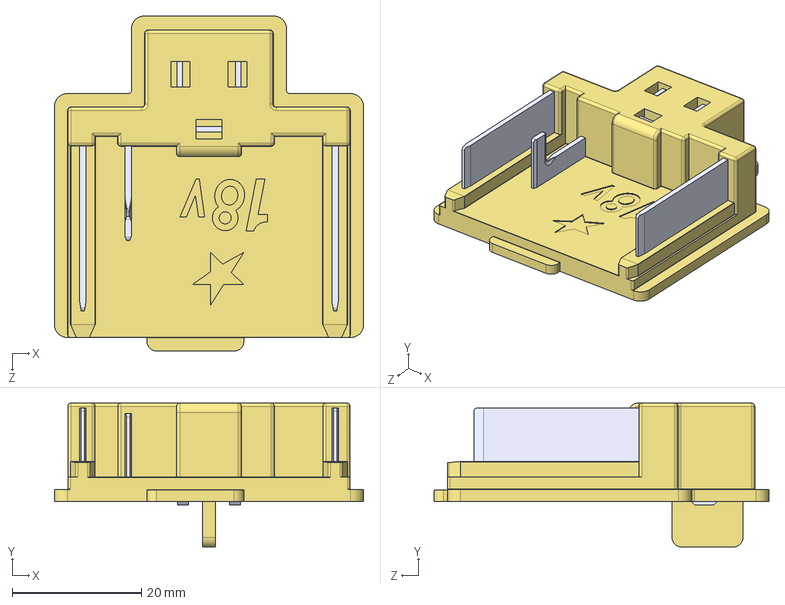
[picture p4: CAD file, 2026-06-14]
references/makita_643852_2.step
47.8 x 22.2 x 51.8 mm

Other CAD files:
references/seaflo_42_pump.stl

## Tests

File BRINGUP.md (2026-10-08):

# Bring-up: the v2 main board, from the envelope to a running pump

**Nothing in this repository described this.** "Bring-up" appeared only in passing —
*"OTA covers everything after bring-up"*, *"ten bring-up pads"* — with no order, no
measurements and no expected numbers. This file is the order, and every step names
what to measure and what it should read.

**Read the stop rule first: at every step, if the number is not the expected one, STOP
and diagnose there.** Each stage exists so that the next one cannot damage anything,
and the staging is not advisory — it is how the two known hazards below are avoided.

## The two hazards this order is built around

**1. A pump can start with no joystick connected.** `JOY_RAW` is J4 way 3 and R22 and
nothing else — no pull-up, no pull-down, no bias. Unlanded, the ADC node floats,
`measureCentre()` calibrates against the float, and drift past `DEADBAND_ON` (300 counts
of 4095, ≈ 0.24 V) for 6 of 10 samples engages a pump. **Mitigation in firmware:** a
board with no stored preference boots **DISARMED**, so a new board will not drive a pump
until you send `a`. **Not yet fixed in copper:** finding 49.

**2. Two power sources can back-feed each other.** J6 pin 1 is the buck's own 3V3 rail.
Landing an adapter's 3V3 while the pack is docked feeds one into the other. Pick one
source per stage, as below.

## Stage 0 — before anything is powered

| measure | where | expect |
|---|---|---|
| VBAT to GND, resistance | TP2 ↔ TP1 | **not a short.** Tens of kΩ and rising as C1/C2 charge off the meter |
| 3V3 to GND, resistance | TP3 ↔ TP1 | **not a short.** Hundreds of Ω at minimum; a dead short here is an assembly fault |
| F2 | the blade holder | **blade OUT.** It isolates the pack from the whole board — see below |

⚠ **WHAT THE BLADE DOES AND DOES NOT STAGE.** VBAT is the far side of F2, and VBAT
carries U1's VIN *and* EN, R9's VGATE dropper, TP2 and both pump terminals. So the blade
out means **the entire board is unpowered** — it is the pack's isolator, nothing finer.
It comes **out** for stages 0 and 1 and goes **in** at stage 2, and from there what keeps
things safe is that nothing which can move is landed and the firmware boots disarmed.

**Two nets have no test pad, on purpose, because a screw terminal is already a probe
point:** VBAT_RAW (J1 to F2, ahead of the blade) is probed at **J1's own screw**, and
VBAT_LVL (F1 to J5, behind the level fuse) at **J5 way 1's screw** — which is how you
tell a tripped F1 from a dead sensor.

Nothing is landed on J1–J5 yet. The ten test pads are net-labelled on the silk:
TP1 GND, TP2 VBAT, TP3 +3V3, TP4 VGATE, TP5 SW, TP6 GATE_A, TP7 GATE_B,
TP8 VBAT_SENSE, TP9 JOY_FILT, TP10 LEVEL.

## Stage 1 — flash it with no pack anywhere near it

Pack **out of the dock**, F2 blade **out**. Power the board from the adapter's 3V3 on
J6 pin 1. This is enough to flash and talk; it is **not** enough to test a pump, because
the gate driver needs VGATE and VGATE comes from the pack.

Wire J6 using the names printed on the **back** silk beside the header:

| J6 | silk | adapter |
|---|---|---|
| 1 | 3V3 | 3V3 |
| 2 | GND | GND |
| 3 | `ESP_TX_TO_PROG` | **RX** |
| 4 | `PROG_RX_IN` | **TX** |
| 5 | `EN` | RTS |
| 6 | `IO0` | DTR |

⚠ **Both serial ways are named from the board's side.** `ESP_TX_TO_PROG` is an *output*
of this board, so it goes to the adapter's RX. Wiring TX to TX by matching labels is the
commonest reason a first flash fails (M26).

| step | expect |
|---|---|
| 3V3 at TP3 | **3.30 V** (the rail is asserted at 3.301 V) |
| `pio run -t upload` | connects and writes. DTR/RTS enter the bootloader by themselves; with an adapter that does not break them out, hold IO0 to GND, pulse EN to GND, release EN, start the upload, release IO0 once it connects |
| `pio device monitor` | boots, and prints **`*** PUMP DISARMED ***`** |
| `?` | lists `a d c s b R` |

**If the upload fails:** the baud is pinned to 115200 for exactly this reason, so
suspect the wiring before the board. Swap pins 3 and 4 as the first experiment.

⚠ **IF IT FLASHES AND THEN REBOOTS IN A LOOP, SUSPECT THE ADAPTER, NOT THE BOARD.**
An adapter's 3V3 usually comes from a small LDO good for 50—100 mA. Flashing is fine
because the radio is off, but `netSetup()` brings WiFi up on the first boot and an
ESP32's transmit peaks run to several hundred mA. The board's own 88 µF of output
capacitance absorbs a transient, not a sustained draw.

The symptom is named rather than silent: arduino-esp32 enables the brownout detector by
default and nothing here disables it, so the console prints **`Brownout detector was
triggered`** before each reset. Seeing that at stage 1 is an underpowered adapter.
**Do not diagnose the board from this stage — move to stage 2 and judge it on pack
power.** `monitor_filters = esp32_exception_decoder` is set so that a genuine panic,
as opposed to a brownout, arrives as a decoded backtrace instead of raw addresses.

**Firmware footprint, measured** (`pio run -e main-usb`, 2026-10-08): builds clean,
**RAM 16.0 %** (52,512 of 327,680) and **Flash 78.3 %** (1,026,150 of 1,310,720). The
flash figure is against ONE app slot of `default.csv`, which carries two so OTA can
swap between them — so the image fits with about 284 KB spare, and that margin is
what an OTA update has to keep fitting into.

## Stage 2 — the pack, still with nothing attached that can move

Adapter 3V3 **off** (leave TX/RX/GND landed to keep the console). **J2/J3 (pumps) empty,
J4/J5 empty** — that, plus the disarmed firmware, is what makes this stage safe.

Dock the pack, then fit **F2's blade**. The board is dead until you do: VBAT is on the
far side of the fuse and feeds U1's VIN, so there is no 3V3 and no VGATE to measure with
the blade out.
⚠ An earlier version of this file said "blade **still out**" here and then asked for
3V3 and VGATE anyway. It is recorded rather than quietly fixed because it is the exact
shape of error a procedure exists to prevent: a state the steps cannot be performed in.

First, with the pack docked and the blade still out:

| measure | where | expect |
|---|---|---|
| pack at the terminal | **J1's screw** ↔ TP1 | **15.0–21.0 V.** 21 V is a fresh pack off the charger, not 20 — a "18 V" Makita is 5S. This is VBAT_RAW, ahead of the fuse, which is why it reads with the blade out |

Then fit the blade, and the rest of the board comes alive:

| measure | where | expect |
|---|---|---|
| pack, board side | TP2 ↔ TP1 | **the same voltage**, within a few mV. A difference here is the fuse or its holder |
| 3V3 | TP3 | **3.30 V** |
| VGATE | TP4 | **10 V**, the zener rail |
| GATE_A | TP6 | **0 V** |
| GATE_B | TP7 | **0 V** |
| VBAT_SENSE | TP8 | **VBAT ÷ 11** — 1.91 V at a 21 V pack, 1.36 V at 15 V |
| `s` | console | `pack=` within ~0.1 V of what the meter says at TP2 |
| `s` | console | `cap=` **255 × 12 ÷ pack** — 146 at 21.0 V, 170 at 18.0 V, 204 at 15.0 V. Below ~12 V it pins at 255 |

**⚠ READ `cap=` HERE, WITH NO PUMP ATTACHED.** It is the only thing standing between a
21 V pack and a 12 V pump, and this is the last stage at which it can be checked for
free — by stage 5 a pump is wired and a cap that is wrong is already turning a motor.
Work it out from the meter: `cap = 255 × 12 ÷ pack`, rounded. If `pack=` is right and
`cap=` is not, the divider constants and the board disagree, which is what
`tools/check_part_values.py` exists to prevent and what put 12.60 V across a 12 V pump
once already (punchlist 53).

Two readings say the pack sense has **failed** rather than drifted, and both are worth
knowing before they are mistaken for something else:

* `pack=` carries a trailing `?` and the boot line says **`SENSE IMPLAUSIBLE - assuming
  a fresh pack`** — the reading fell outside 10–22 V, so the firmware assumed the
  *top* of the range (21.0 V, the worst case) and capped accordingly. That is the safe
  direction: assuming a *lower* pack would RAISE the cap.
* `cap=255` with a pack above 12 V — the cap is not capping. Suspect R20/R21 or TP8.

**GATE_A and GATE_B at 0 V is the one to dwell on.** They are held there three
independent ways — the UCC27517 holds its output low with its input floating (SLUSAY4D),
its VDD UVLO holds it low below 4.5 V, and R6/R7 put 100 kΩ from each gate to GND. If
either reads anything but 0 V with the board disarmed, stop: that is the fault that
drives a pump you did not ask for.

## Stage 3 — the level sensor

Land J5, **four wires, four ways, straight across** — brown VBAT, yellow OUT, blue GND,
black MODE. The labels are the instructions; this was not always true, and the old build
note's wiring inverts the alarm (finding 47).

| measure | state | expect |
|---|---|---|
| TP10 | **J5 empty** | **≈3.3 V**, and `b` reports `FULL` — a disconnected sensor reads full *on purpose*, so a dead sensor stops the pump |
| TP10 | sensor landed, **dry** | **≈0 V**, `b` reports `pin=LOW -> not full` |
| TP10 | sensor **wet** | **≈3.3 V**, `b` reports `pin=HIGH -> FULL` |
| `b` | any | buzzer sounds for 1 s |

⚠ **If full reads backwards, do not flip `LEVEL_FULL_IS_LOW`.** Check 9 of
`tools/check_level_alarm.py` derives that constant from the netlist and will fail, and it
was never the remedy: the constant describes the board, so a backwards reading means the
board is not wired as drawn. Look at the black MODE wire first, then Q4/R29/R30, then the
300 kΩ string R23/R27/R28.

## Stage 4 — the joystick

Land J4. Only way 3 (VRY) is live; ways 2, 4 and 5 are tied to GND on the board.

| step | expect |
|---|---|
| TP9 at rest | **≈1.65 V**, about half the rail |
| `c` | recalibrates; leave the stick at rest while it runs |
| `s` | `centre=` near 2048 of 4095, and `joy rawoff=` within the deadband (±300) |
| push one way | `rawoff=` goes past **+300**; the telemetry line shows `offset=+...` |
| push the other | `rawoff=` goes past **−300** |

⚠ **IF `a` IN THE NEXT STAGE PRINTS `*** ARM REFUSED ***`, THIS IS THE STAGE IT IS
TALKING ABOUT.** A centre outside **1200–2900** is not a centre measured on a resting
stick, and the firmware now refuses to arm on it rather than warning and arming anyway
— the status line reads `DISARMED/NO-CENTRE` and a board whose *stored* state was armed
is disarmed on boot with a message. The remedy is in the message: land J4, let go of the
stick, `c`, then `a`. It exists because of punchlist 49, which is **open**: `JOY_RAW` has
no pull of any kind, so an unlanded lead leaves the ADC node floating and the calibration
lands on whatever it floats to. The copper fix is two 100k biasing it to mid-rail and is
deliberately not in this revision; refusing to act on a calibration that cannot be right
is the half that costs nothing.

⚠ **`dir=` STAYS `none` THROUGHOUT THIS STAGE, AND THAT IS NOT A FAULT.** An earlier
version of this file told you to watch `s` report `dir=A` and `dir=B` here. It never
will while disarmed: the direction vote sits inside `if (armed && !otaActive)` in
`loop()`, so nothing computes a direction when the motor is inhibited. Judge the stick
by **`rawoff=`**, which is live either way — `+300` and `-300` are `DEADBAND_ON`, the
same threshold the vote uses once armed. `s` says so in its own output now, and the
periodic telemetry line carries `raw= filt= offset=` with a `[DISARMED]` marker.

Recorded rather than quietly corrected, for the same reason as stage 2: a step that
cannot be performed in the state it specifies is the defect a procedure exists to
prevent, and this file shipped with two of them.

Confirm both deflections here, disarmed, before anything can turn. **Which deflection
drives which pump is only provable at stage 5**, with a pump landed — getting A and B
swapped is a wiring error, not a firmware constant, and
`tools/check_pump_dirs.py` owns the firmware side.

## Stage 5 — first pump motion

Only now: F2 blade **in**, and land **one** pump (J2). Keep the tank lines where a
wrong direction spills into a bucket rather than into the electronics.

| step | expect |
|---|---|
| `a` | `*** PUMP ARMED ***` — or `*** ARM REFUSED ***`, which is stage 4's centre, not a fault here |
| brief deflection toward A | pump A runs; `s` shows `state=ARMED dir=A duty=` ramping |
| release | stops within the off-latency `s` reports (~15 ms) |
| **while it runs** | **J2's two screws, DC volts** ↔ each other: **≈ 12 V**, *not* the pack |
| `d` | `*** PUMP DISARMED ***`, and it stays disarmed across a reboot |

**⚠ THAT 12 V IS THE WHOLE PROTECTION, MEASURED AT THE MOMENT IT MATTERS.** The pumps
are 12 V parts on a 15–21 V pack, and nothing drops the difference — the duty cap
synthesises it, so the average across the motor is `duty ÷ 255 × pack`, which is 12 V by
construction (stage 2's `cap=` row). A DC meter averages the 20 kHz chop, and the
freewheel diode holds the off-time near 0 V, so an ordinary multimeter is the right
instrument here. **If it reads the pack voltage instead, stop and disarm**: the cap is
not being applied and the pump is at 1.75× its rating. That is `cap=255` from stage 2
arriving at a motor, and it is the failure punchlist 53 found in the firmware's own
fallback.

Then land J3 and repeat for B. The killswitch at the dock is a **switch, not a fuse** —
it opens when a person opens it. F2 is the fuse.

## Stage 6 — the network, and OTA

With USB still attached, `s` prints `rssi=` and `ip=`. Once an IP appears,
`pio run -e main-ota -t upload` works and the adapter is no longer needed.

**If it flashes and runs but never gets an IP**, in the order worth trying:

| check | meaning |
|---|---|
| no IP, and no usable `rssi=` | the radio never associated — credentials or band |
| `s` shows a real `rssi=` but no IP | associated, no DHCP lease — a router or VLAN problem, not this board |
| `rssi=` worse than about −80 dBm | it is a link-budget problem; see the antenna note below |
| the console is silent after `Brownout detector was triggered` | not a network fault at all — stage 1's underpowered-adapter case |

Two causes are specific to this board and worth knowing before you suspect the radio:

* **The credentials are not in the repository.** `firmware/src/secrets.h` is gitignored,
  so a fresh clone has no SSID or password and the board will come up, run, and never
  associate. That is the expected behaviour of a clone, not a fault.
* **The ESP32 is 2.4 GHz only.** A 5 GHz-only SSID, or a band-steering router that hands
  out one name for both, looks exactly like wrong credentials.

**The antenna has a measured keepout and it is the board outline, not a rule area.** The
module's relief is the 4.6 × 4.6 mm cutout at x 140.70–145.30, y 47.70–52.30 in board
coordinates (15.9 mm², which `finish.py` checks every run). There are **no copper rule
areas on this board at all**, so nothing but that cutout keeps copper out from under the
antenna — which is why finding 39 cut the board back rather than drawing a keepout.

**Everything up to here works without a network.** Nothing in stages 0–5 needs WiFi, so
a board that fails only this stage is a usable board with a network problem, and the
pumps, the sensor and the alarm have all already been proven on the console.

⚠ **OTA authentication is OFF** (`OTA_PASSWORD` is empty in `src/secrets.h`), so anyone
on the LAN can reflash the board. `platformio.ini` says how to turn it on.

## What this procedure cannot tell you

* **Effective capacitance under DC bias** — stated as an open item under M15.
* **The dock's contact rating** — not in this repo; M16 explains why neither quantity
  that matters depends on it.
* **Active/NRND part status** — an order-time check, not a bench one (M42).

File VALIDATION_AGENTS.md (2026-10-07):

# Pre-order validation — four independent passes, run by agents

**Status: QUEUED.** Runs after (1) the terminal row lands on the −Y edge and
(2) the internal wiring is modelled. The owner set that order.

Source: the pedal steel lead's pre-order checklist. It is written for that
project's boards — several bench boards, an STM32 and some CH32V parts — so it is
**adapted** here rather than copied. This repo has one board and one MCU.

**Why "after" is also right engineering, not just the owner's call:** passes 1–3
read the *netlist*, which the J5 work does not change, but pass 4 and any placement
claim read the CPL, which it does. Reviewing a placement that is about to move
would produce a report that is stale before it is read. The netlist being stable
is also why these four can all start the moment the merge lands.

**The point of an agent here is ignorance.** Each reviewer gets what the *fab*
gets — netlist, BOM, placement — plus the makers' datasheets, and must not read
`elec/main.py`. A reviewer who has read the generator will re-derive the
generator's own assumptions and agree with them. That agreement is worth nothing;
it is the same mistake as a hand-typed copy of the board agreeing with itself,
which this repo already has scars from.

---

## 1. Pin-by-pin review against the datasheets

One reviewer, no knowledge of the generator. For **every** chip and connector,
write a row: `pin number → datasheet pin name → net`, and flag anything that
contradicts the maker's reference circuit.

Parts: U1 LMR14020SDDA, U2 ESP32-WROOM-32E, U3/U4 UCC27517, Q1/Q2 (TO-252),
D1 SMCJ24A, D2/D3 (TO-263), J1–J6, F1, F2, BZ1.

Hunting specifically for the classic first-spin killers:

* a package variant whose pin order differs from the one assumed
* a **bottom view read as a top view** — the single most expensive drawing error
* an enable or mode pin left floating that the datasheet requires driven
* a feedback divider that sets the **wrong output voltage**

That last one has a live hook here: the buck's feedback is 100k over 29k4, and
`elec/main.py` derives it as `100k × 0.75 / (3.3 − 0.75) = 29.41k`. The reviewer
should derive the output voltage **from the datasheet's own equation and the
parts on the BOM**, and say what it comes to — not check the arithmetic already
written down.

## 2. ESP32 pin-function check

The lead's version uses CubeMX for the STM32 and WCH's tables for the CH32V. Ours
is an **ESP32-WROOM-32E**, so the equivalent is Espressif's datasheet v2.1 pin
tables plus the module's own restrictions. Every signal must land on a pin that
can actually perform its function:

* **ADC2 cannot be read while WiFi is on.** This board has two analogue inputs —
  VBAT_SENSE and JOY_FILT — and a WiFi part. If either sits on an ADC2 pin, that
  is a re-spin, not a firmware workaround.
* **GPIO34–39 are input-only** and have no pull-ups. Anything driven on those is
  dead silicon.
* **GPIO6–11 are the module's internal flash bus** and are not ours to use.
* **Strapping pins** (0, 2, 5, 12, 15) must boot to the right state — M8 already
  argues this, so the reviewer should test the argument, not restate it.

Deliverable is the **pin-setup firmware**, written now: it is the check and it is
the start of the firmware this machine needs anyway. `firmware/` already exists.

## 3. Voltage on every pin against its rating — A NEW RULE

The lead is right that no rule covers this. A scripted pass assigns every net its
worst-case voltage and fails any pin rated below it.

Worst case on this board is **not** the nominal 18 V: a fresh Makita LXT pack is
~20 V, and D1 is a 24 V TVS chosen to clamp above that. Bands: VBAT / VBAT_RAW /
VBAT_LVL and the two motor legs at 20 V (24 V clamped), +3V3 at 3.3 V, VGATE at
its Zener, GND at 0.

⚠ **This belongs in canonical `../cadkit`, not the vendored copy.** Adding a rule
by hand to `cadkit/` here is exactly the drift that collided with the pedal steel
project's A13 and cost a day. Edit canonical, commit, then
`py -3.12 ../cadkit/tools/propagate.py`. Take the next free rule ID there — do not
assume one. And **make it fail before believing it**: a 20 V net on a 16 V part, a
pin with no rating at all, and a board where every rating is absent should each
produce a different answer.

## 4. Custom footprints against the datasheet land pattern

Everything in this repo's own library was drawn by hand and has never been checked
against a maker's recommended land pattern. JLCPCB's previewer covered the parts
whose placement frames fitted automatically; it did not cover these.

* `wbp:SOIC-8-1EP-FABDRILL` — U1's land, including the six 0.3 mm thermal vias
  through the exposed pad
* `wbp:ESP32-WROOM-32E-FABDRILL` — U2, including the twelve 0.7 mm plated holes
  in the thermal pad and the antenna keepout
* the three whose frames the automatic pad-**number** fit refused and which were
  resolved by hand on pad **position**: `TO-252-3_TabPin2` (Q1/Q2),
  `TO-263-2` (D2/D3), `FuseHolder_Blade_ATO_Littelfuse_FLR_178.6165` (F2)

For the last three the hand reasoning is in `elec/fab_frames.json` under each
entry's `by` field. The reviewer should check the **land against the datasheet**,
which is a different question from whether our land matches the fab's library —
both can agree and both still be wrong.

---

## Reporting

Each agent returns findings only, with the datasheet page or table cited for every
claim. A finding with no citation is an opinion. Findings land in
`WORK_V2_PUNCHLIST.md`, numbered, and anything accepted rather than fixed is named
and measured — never lumped.

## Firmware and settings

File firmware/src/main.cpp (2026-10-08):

/*
 * Watering-backpack pump controller — v2 board
 * ESP32-WROOM-32E + two low-side pump FETs + single-axis analog joystick.
 *
 * TWO PUMPS, ONE AXIS. A diaphragm pump cannot be reversed — its check valves
 * are passive — so DESIGN_V2.md §1 puts two of them in anti-parallel across
 * shared tees and direction becomes which pump you run:
 *
 *     stick hard FORWARD -> pump A, tank -> pot   (water the plant)
 *     stick hard BACK    -> pump B, pot  -> tank  (suck the line back)
 *     stick near centre  -> neither
 *
 * The idle pump's own check valves seal its branch. Running both at once would
 * make them fight through the shared tees and pull 2 x 7.5 A off one pack, so
 * the interlock is structural: drivePumps() is the only thing that can raise a
 * gate, and it writes BOTH pins on every call. Every direction change also
 * passes through "neither" and waits out DIR_DEAD_MS, so there is no A->B edge
 * in the state machine at all.
 *
 * tools/check_pump_dirs.py drives traces through a transcription of that state
 * machine — including the flick straight from hard-forward to hard-back, which
 * crosses the release band faster than the release vote can see it.
 *
 * PUMP VOLTAGE IS REGULATED. The pumps are 12 V and the pack is 15-21 V, so the
 * duty ceiling tracks the pack through the VBAT divider on IO35 and holds the
 * average armature voltage at 12 V (see "Pump voltage regulation"). Until this
 * existed, RUN_DUTY was PWM_MAX and every engage put the whole pack across a
 * 12 V pump.
 *
 * THIS IS NOW v2-ONLY. It will not drive v1's QuinLED + BTS7960 rig: that had
 * one pump and a manual X-port valve, and the enable pin this used to hold HIGH
 * (IO4) is connected to nothing on the v2 board, so it is gone.
 *
 * TANK-FULL ALARM. IO14 reads the capacitive level sensor and IO27 beeps the
 * buzzer while it reads full. That is the spigot-fill overflow alarm from
 * elec/CIRCUIT.md §5 — "filling happens with the pump OFF and the user standing
 * at the tank" — so it runs independently of `armed`, which inhibits the pumps.
 *
 * It is deliberately NOT an interlock on either pump. DESIGN_V2.md §7 accepts
 * false positives because for FILLING they are cheap ("stop early, look, carry
 * on"), but a false positive that blocked pump B would block retract, leaving a
 * primed line to drip — not cheap, and not a trade that section asked for.
 *
 * The debounce is asymmetric and tools/check_level_alarm.py is where it is
 * checked: the tank rides on someone's back and §7 puts the sensor BELOW the
 * full line on purpose, so the threshold gets crossed early and often.
 *
 * Pins, from elec/main.py — the schematic is the authority, not this comment:
 *   IO26  -> pump A gate driver   (tank -> pot)
 *   IO25  -> pump B gate driver   (pot  -> tank)
 *   IO35  -> VBAT_SENSE, off the R20/R21 divider (ADC1, input-only)
 *   IO34  -> joystick SIG, after its RC filter   (ADC1, input-only)
 *   IO14  -> tank level, through Q4's inverting collector, pulled up by the 300k
 *            string R23/R27/R28 and fed through R26 (NOT "R23, a 10k to 3V3",
 *            which is what this line said and no part of which was true)
 *   IO27  -> buzzer, through Q3
 *   EN / IO0 / RXD0 / TXD0 -> programming header
 *
 * ── NOISE REJECTION ──────────────────────────────────────────────────────────
 * This joystick's wiper sits on ~100 counts of RMS noise (peaks past +-450),
 * roughly 7x a healthy pot. Measured characteristics that drove the design here:
 *
 *   - Noise is WHITE: mean|sample-to-sample diff| / stdev came out at 1.128, the
 *     exact ratio for uncorrelated Gaussian noise. So it averages down as sqrt(N)
 *     and its excursions are single-sample events.
 *   - Excursions over the deadband last 1-2 samples (never longer).
 *   - Noise amplitude is FLAT across stick travel and does NOT scale with wiper
 *     position, which excludes both pot source impedance and 3V3 supply noise,
 *     and points at the ground reference. It is a hardware fault; everything
 *     below is a workaround that makes the controller immune to it, not a cure.
 *
 * The original failure mode was noise RECTIFYING into motion: the control law
 * was forward-only, so symmetric noise became a one-sided command, and the ramp
 * integrator ratcheted those one-sided kicks upward into a slow, self-sustaining
 * pump creep. The control law now closes that off:
 *
 * (The law is no longer one-sided -- reverse is live -- so symmetric noise no
 * longer rectifies. It does mean there are now TWO ways to false-trigger rather
 * than one, so the spurious-engage rate below doubles: ~1.2e-10 per window
 * instead of ~6e-11, or roughly one per year of continuous running instead of
 * one per two. Both are noise against the vote clearing it in ~25 ms, and a
 * spurious REVERSE while a pump is running only ever stops it, which is the
 * safe direction.)
 *
 *   1. K-of-N MAJORITY VOTE on the raw samples decides on/off. Because the noise
 *      is white, samples are independent, so requiring 6 of the last 10 samples
 *      past the threshold drives the false-trigger rate to ~1 per 2 years while
 *      costing only a 50 ms window. A smoothing filter would have needed ~185 ms
 *      of lag for worse rejection.
 *   2. HYSTERESIS — separate engage (300) and release (180) thresholds, so the
 *      decision cannot chatter at the boundary.
 *   3. NO INTERMEDIATE DUTY. The stick is used hard-forward or hard-back, so
 *      engaged means RUN_DUTY and nothing else. A slow trickle is no longer a
 *      state the controller can represent, which is a stronger guarantee than
 *      making it improbable.
 *   4. The ramp integrator no longer spans the on/off edge — it only shapes the
 *      soft start. Stopping is an immediate cut, which is both the responsive and
 *      the safe direction.
 *
 * Switch-on latency is ~50 ms of vote plus ~105 ms of soft-start ramp; switch-off
 * is ~25 ms and immediate.
 *
 * ── REMOTE DEBUG ─────────────────────────────────────────────────────────────
 * WiFi is strictly a diagnostic side-car. The control loop runs first and
 * unconditionally, so the backpack works with no network, a wrong password, or no
 * AP in range — nothing on the control path blocks on WiFi.
 *
 *   OTA flashing : ArduinoOTA. Motor forced OFF before an update is accepted.
 *   Telemetry    : raw TCP on port 23. Reports stats over EVERY loop sample
 *                  (~200/s) for BOTH the raw and filtered signals, so the
 *                  filter's effect can be measured directly.
 *   ARM / DISARM : `d` inhibits the motor while telemetry keeps running. Stored
 *                  in NVS and SURVIVES REBOOT — an OTA push reboots the board,
 *                  and coming back armed mid-test would spray water.
 *
 * ADC1 is used for the joystick (GPIO34) — the half of the ESP32 ADC that stays
 * usable while the radio is on.
 */
#include <Arduino.h>
#include <WiFi.h>
#include <ESPmDNS.h>
#include <ArduinoOTA.h>
#include <Preferences.h>
#include <math.h>
#include "secrets.h"
#include "pins.h"

// ── Pin map ──────────────────────────────────────────────────────────────────
// Lives in pins.h, which carries the module-pin table out of elec/out/main.net
// and the datasheet reason for every pin's mode. JOY_PIN, VBAT_PIN, LEVEL_PIN,
// BUZZ_PIN, PUMP_A_PIN, PUMP_B_PIN, PWM_FREQ, PWM_RES and ADC_RES come from
// there; pinsInit() in pins.cpp is what configures them.
//
// One low-side MOSFET per pump, each behind its own non-inverting gate driver,
// so PWM high = that pump runs. No H-bridge and NO ENABLE PIN: a diaphragm pump
// cannot be reversed (DESIGN_V2 §1 — the check valves are passive), so direction
// is WHICH PUMP YOU RUN. v1's EN on IO4 is connected to nothing on the v2 board
// and is gone.

// ── PWM (LEDC, pin-based API = Arduino-ESP32 3.x) ────────────────────────────
constexpr int PWM_MAX  = (1 << PWM_RES) - 1;
constexpr int DUTY_CAP = PWM_MAX;            // lower to cap max pump speed (e.g. 200)

// ── Pump voltage regulation ──────────────────────────────────────────────────
// The pumps are 12 V. The pack is 15-21 V. elec/CIRCUIT.md §1: "Duty is capped
// in firmware to synthesise 12 V from a 15-21 V pack. PWM already chops the
// supply, so the motor does not care -- but the cap must track the pack voltage,
// which is what the divider below is for."
//
// Nothing was tracking it. RUN_DUTY is PWM_MAX, so every engage put the whole
// pack across a 12 V pump: 1.7x rated on a fresh one. The divider has been on
// the board the entire time -- R20/R21 into IO35, with C11 across the bottom leg
// (100k/18k when this was written, 100k/10k since finding 33) -- and no line of
// firmware read it.
//
// For a PWM'd brushed motor with a freewheel path the average armature voltage
// is duty x V_pack, which is what makes the cap a one-liner:
//
//     pack 20.0 V -> cap 153  (60 %)
//     pack 18.0 V -> cap 170  (67 %)
//     pack 15.0 V -> cap 204  (80 %)
//
// CIRCUIT.md gives the divider a second job as well -- "expose sag in telemetry.
// This would have diagnosed v1's mid-run slowdown in thirty seconds" -- so the
// pack voltage and the live cap are both on the 's' status line.
constexpr float PUMP_V_NOM  = 12.0f;         // pump nameplate
constexpr float RDIV_TOP_K  = 100.0f;        // R20, from elec/main.py
// !! 10k, AND IT WAS 18k HERE LONG AFTER THE BOARD STOPPED BEING 18k. Punchlist
// finding 33 took R21 to 10k (elec/main.py RDIV_TOP, RDIV_BOT) to keep the whole
// 15-21 V range inside the ADC's linear band. The punchlist claimed "the quality
// declaration, the assert and THE FIRMWARE'S SCALING all follow automatically"
// from that one constant. The first two do. This one is hand-typed, and it did
// not follow.
//
// What a stale 6.5556 did, measured across the pack range:
//
//   real pack   IO35     this file read   plausible?   duty cap   motor saw
//   15.00 V     1.364    8.94 V           NO -> 20 V   153        9.00 V
//   16.78 V     1.525    10.00 V          yes          255        16.78 V
//   20.00 V     1.818    11.92 V          yes          255        20.00 V
//
// Above ~16.8 V the cap saturates at PWM_MAX and every engage puts the WHOLE PACK
// across a 12 V pump -- 1.67x rated, which is verbatim the failure the comment
// below says this cap exists to prevent. Below that it reads as a divider fault
// and under-drives instead. A fresh pack would most likely have blown the 10 A
// ATO blade before it cooked the pump, which is luck, not design.
//
// !! THIS CONSTANT IS A COPY OF A BOARD VALUE AND NOTHING COMPARES THEM.
// tools/check_pin_map.py ties this firmware to the schematic, but only by PIN
// NUMBER -- it never reads a component value, so no gate in the repo covers this
// line. If the divider moves again, this is the second place to change.
constexpr float RDIV_BOT_K  = 10.0f;         // R21
constexpr float VBAT_SCALE  = (RDIV_TOP_K + RDIV_BOT_K) / RDIV_BOT_K;   // 11.000
// Plausibility window. An open divider reads ~0 and a shorted one reads full
// scale, and in either case the cap falls back to the value for the HIGHEST
// expected pack -- the LOWEST duty. A sensor fault must never be able to raise
// the duty, which is why the fallback is not PWM_MAX.
constexpr float VBAT_PLAUS_LO = 10.0f;
// ⚠ BOTH OF THESE WERE SET AGAINST A 20 V PACK AND THE BOARD NOW ADMITS 21.0.
// VBAT_PLAUS_HI said "the divider saturates at 21.6", which was the 18k divider's
// number (3.3 V x 6.5556); at 100k/10k the pin reaches 3.3 V only at a 36 V pack
// and the ADC's characterised top of 2.450 V corresponds to 26.9 V, so nothing
// saturates near this window. 22.0 survives as the window top because it is just
// above elec/main.py's VBAT_MAX, which is the reason it should have given.
constexpr float VBAT_PLAUS_HI = 22.0f;       // > VBAT_MAX (21.0) with 1 V to spare
// ⚠ AND 20.0 HAD STOPPED BEING THE SAFE END. This is the assumption used when the
// sense path reads implausibly, and it sets the duty cap: cap = PWM_MAX x 12 / v,
// so assuming LESS than the real pack raises the cap. With VBAT_MAX at 21.0 a 20.0
// assumption capped at 153 and put 12.60 V across a 12 V pump -- a 5 % overdrive in
// exactly the fault case the cap exists for. The safe assumption is the TOP of the
// range, never the middle. tools/check_part_values.py reads VBAT_MAX out of
// elec/main.py and fails if this drops below it again.
constexpr float VBAT_ASSUMED  = 21.0f;       // = VBAT_MAX: the worst case, not a guess
constexpr int   VBAT_EVERY_N  = 20;          // 5 ms loop -> read every ~100 ms
constexpr float VBAT_EMA_A    = 1.0f / 16.0f;   // slow; the pack sags slowly

// ── Joystick / control tunables ──────────────────────────────────────────────
constexpr int ADC_MAX   = (1 << ADC_RES) - 1;   // 4095  (ADC_RES: pins.h)
// Soft-start rate, in duty counts per 5 ms loop. This shapes only the RISE to full
// speed; it is NOT on the switch-on latency path in any meaningful sense and it is
// not used at all when stopping (stopping is an immediate cut). Keeping some ramp
// matters: slamming a stalled pump motor to full duty draws several times running
// current, and the resulting battery sag can brown out the ESP32 through the TSR.
// 12 gives ~105 ms from stopped to full. The original firmware used 4 (~320 ms),
// which already felt instantaneous, so there is margin to slow this down if the
// pump ever trips the supply.
// The ramp IS the flow control. There is no proportional stick, so dose is set by
// how long the stick is held: a quick flick gives a small plant a splash-free
// trickle, a longer hold winds up to full.
//
// START_DUTY is the duty the pump snaps to the instant it engages — the floor below
// which this pump does not push useful water, so a flick lands ON it rather than
// somewhere underneath it where nothing comes out. It therefore sets the SMALLEST
// dose a flick can deliver. RAMP_MS sets how fast it climbs above that floor.
//
// Resulting dwell -> duty, at these values:
//     flick ~200 ms ->  79 (31%)    ~400 ms -> 123 (48%)
//           ~700 ms -> 189 (74%)    1000 ms+ -> 255 (full)
//
// Both are estimates — the pump's true minimum useful duty has never been measured,
// and START_DUTY is the likelier of the two to be wrong. The previous value ramped
// to full in 106 ms, which made every flick a full-power burst.
// REVERTED to the pre-dose-metering behaviour at the user's request, while an
// unexplained mid-run slowdown is investigated. These two values reproduce the old
// integer ramp exactly: (255<<8)*5/106 = 3079 Q8 = 12.03 duty counts per 5 ms loop,
// which was the old RAMP_STEP of 12. A flick is once again a full-power burst.
//
// NOTE: telemetry taken under load shows this revert cannot be the cause of that
// slowdown — duty ramped 42/93/146/200/255 and then held at 255 for ~8 s until
// release, with one engage transition and no dip. Restore RAMP_MS=1000 /
// START_DUTY=35 to get dose metering back.
constexpr int RAMP_MS    = 106;              // time from START_DUTY to full
constexpr int START_DUTY = 0;                // no floor — ramp from a standstill

// Duty is carried in Q8 fixed point because the useful rates are fractions of a duty
// count per 5 ms loop: this ramp is 0.73 counts/loop, which integer stepping cannot
// represent at all — it would floor to 0 and the ramp would never start.
constexpr int32_t RAMP_STEP_Q8 =
    ((int32_t)(PWM_MAX - START_DUTY) << 8) * 5 / RAMP_MS;
static_assert(RAMP_STEP_Q8 >= 1, "ramp rounds to zero — RAMP_MS too large");
static_assert(START_DUTY >= 0 && START_DUTY < PWM_MAX, "START_DUTY out of range");

// ── TWO SEPARATE SIGNAL PATHS ────────────────────────────────────────────────
// On/off responsiveness matters; fine speed control does not. Those two jobs have
// opposite filtering needs, so they get separate paths off the same ADC reading:
//
//   FAST PATH  (on/off)  — K-of-N majority vote on the RAW samples. No smoothing
//                          filter, so no filter lag. Latency is just the vote
//                          window: ~30-50 ms to start, ~15-25 ms to stop.
//   SMOOTH PATH (duty)   — median + EMA. Lag here is harmless: the pump's own
//                          inertia and the soft-start ramp dominate anyway.
//
// A smoothing filter on the on/off decision would have cost ~185 ms of lag. The
// vote gets BETTER noise rejection than that filter for a fraction of the delay,
// because a binary decision can exploit the fact that the noise is white and
// therefore independent sample to sample (measured: hf/sd = 1.128).
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
void loop() {
  // ── Control law: runs first, every pass, regardless of network state ───────
  int raw  = analogRead(JOY_PIN);
  int filt = filterSample(raw);

  // Pack voltage, decimated. It moves on the scale of minutes, and the joystick
  // owns the fast path on the same ADC block.
  static uint8_t vbatTick = 0;
  if (++vbatTick >= VBAT_EVERY_N) { vbatTick = 0; readVbat(); }

  // Tank level and its alarm. Deliberately NOT an interlock on either pump --
  // see the note above readLevel's constants and the header.
  readLevel();
  updateBuzzer();

  int rawOffset  = raw  - joyCentre;   // drives the on/off vote — the control path
  int offset     = filt - joyCentre;   // diagnostic only, reported but never acted on
  lastRaw = raw; lastFilt = filt; lastRawOffset = rawOffset; lastOffset = offset;

  // ── Fast path: K-of-N majority vote, no smoothing, so no filter lag ───────
  // Three histories now, because both polarities are live. The release vote is
  // on the MAGNITUDE -- it used to be a signed "fell below +180", which quietly
  // meant any rearward deflection read as released, which is exactly how
  // forward-only was implemented.
  static uint16_t fwdHist = 0, revHist = 0, nearHist = 0;
  fwdHist  = (uint16_t)((fwdHist  << 1) | (rawOffset >  DEADBAND_ON ? 1 : 0));
  revHist  = (uint16_t)((revHist  << 1) | (rawOffset < -DEADBAND_ON ? 1 : 0));
  nearHist = (uint16_t)((nearHist << 1) | (abs(rawOffset) < DEADBAND_OFF ? 1 : 0));
  int nFwd  = __builtin_popcount((unsigned)(fwdHist  & ((1u << VOTE_N_ON)  - 1)));
  int nRev  = __builtin_popcount((unsigned)(revHist  & ((1u << VOTE_N_ON)  - 1)));
  int nNear = __builtin_popcount((unsigned)(nearHist & ((1u << VOTE_N_OFF) - 1)));

  Dir wasDir = runDir;
  if (runDir == DIR_NONE) {
    bool fwd = (nFwd >= VOTE_K_ON), rev = (nRev >= VOTE_K_ON);
    // Both votes passing at once is not physically possible on one axis, so it
    // means something is wrong with the stick or its wiring. Start neither.
    if (fwd != rev &&
        (!everStopped || (millis() - lastStopMs) >= DIR_DEAD_MS)) {
      runDir = fwd ? DIR_A : DIR_B;
    }
  } else {
    // Release on the near vote OR on the opposite direction's engage vote. That
    // second clause is not belt-and-braces: a fast flick from hard-forward to
    // hard-back crosses the +-DEADBAND_OFF band in well under the 25 ms the
    // near vote needs, and without it the pump would keep running the WRONG WAY
    // with the stick held hard over the other side.
    bool opp = (runDir == DIR_A) ? (nRev >= VOTE_K_ON) : (nFwd >= VOTE_K_ON);
    if (nNear >= VOTE_K_OFF || opp) {
      runDir = DIR_NONE; lastStopMs = millis(); everStopped = true;
    }
  }
  // Every direction change therefore passes through DIR_NONE and waits out
  // DIR_DEAD_MS. There is no A->B edge anywhere in this state machine.
  bool engaged    = (runDir != DIR_NONE);
  bool wasEngaged = (wasDir != DIR_NONE);

  // Engaged means run at RUN_DUTY; there is no intermediate level, so neither
  // pump can sit at the slow trickle that started all this. That failure mode
  // stays structurally impossible rather than merely unlikely.
  //
  // Capped by the pack voltage, not just RUN_DUTY. The ramp has to respect it
  // too: clamping only inside drivePumps would let dutyQ8 wind up to 255 and
  // sit there, so the moment a sagging pack raised the cap the output would
  // jump instead of ramping.
  int target = engaged ? min(RUN_DUTY, vbatCap) : 0;

  if (armed && !otaActive) {
    if (!engaged) {
      dutyQ8  = 0;                     // switch-off: immediate cut, no spin-down ramp
      curDuty = 0;
    } else {
      if (!wasEngaged) {
        // Snap to the useful-flow floor, then wind up from there. A flick lands
        // ON this value rather than somewhere below it where nothing comes out.
        dutyQ8 = (int32_t)START_DUTY << 8;
      } else if (dutyQ8 < ((int32_t)target << 8)) {
        dutyQ8 += RAMP_STEP_Q8;
        if (dutyQ8 > ((int32_t)target << 8)) dutyQ8 = (int32_t)target << 8;
      }
      curDuty = (int)(dutyQ8 >> 8);
    }
    drivePumps(runDir, curDuty);
  } else {
    // Disarmed or mid-OTA: motor off, but keep reading and reporting the joystick
    // so it can be characterised with no water moving.
    if (curDuty != 0) allStop();
  }

  if (engaged && !wasEngaged) stats.engages++;
  stats.add(raw, filt, rawOffset, offset, curDuty);

  // ── Telemetry ─────────────────────────────────────────────────────────────
  static uint32_t last = 0, lastStats = 0;
  if (millis() - last > LINE_MS) {
    last = millis();
    logf("raw=%4d filt=%4d offset=%+5d duty=%+4d %s%s\n", raw, filt, offset, curDuty,
         runDir == DIR_A ? "A tank>pot" : runDir == DIR_B ? "B pot>tank" : "off       ",
         armed ? "" : " [DISARMED]");
  }
  if (millis() - lastStats > STATS_MS) {
    lastStats = millis();
    logf("STATS n=%lu raw=%d..%d mean=%.1f sd=%.1f hf=%.1f fsd=%.1f fhf=%.1f "
         "over_deadband=%lu fover=%lu maxrun=%lu dutymax=%d engages=%lu\n",
         (unsigned long)stats.raw.n, stats.raw.mn, stats.raw.mx, stats.raw.mean,
         stats.raw.sd(), stats.raw.hf(), stats.filt.sd(), stats.filt.hf(),
         (unsigned long)stats.rawOver, (unsigned long)stats.filtOver,
         (unsigned long)stats.maxRun, stats.dutyMax, (unsigned long)stats.engages);
    stats.reset();
  }

  netLoop();
  delay(5);
}

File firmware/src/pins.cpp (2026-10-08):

/*
 * pins.cpp — one line of setup per pin, and the reason it is legal next to it.
 *
 * Citation keys are defined at the top of pins.h (NET, DS-M, DS-C, IDF).
 *
 * ─────────────────────────────────────────────────────────────────────────────
 * §1  ADC UNIT AND CHANNEL FOR BOTH ANALOGUE INPUTS  — the one that would be a
 *     board re-spin, so it is stated first and exactly.
 *
 *     VBAT_SENSE  NET: U2 pin 7   DS-M Table 3: "IO35  7  I  GPIO35, ADC1_CH7,
 *                 RTC_GPIO5"                      ->  ADC *1*, channel 7
 *     JOY_FILT    NET: U2 pin 6   DS-M Table 3: "IO34  6  I  GPIO34, ADC1_CH6,
 *                 RTC_GPIO4"                      ->  ADC *1*, channel 6
 *
 *     Both are on ADC1. IDF, "Hardware Limitations": "ADC2 is also used by
 *     Wi-Fi." Nothing on this board's analogue path touches ADC2, so WiFi
 *     telemetry and OTA cost nothing. This is the pass, not a workaround.
 *
 *     For completeness, the ADC2 pads that ARE populated on this board carry
 *     digital signals only: IO14 (ADC2_CH6) is read with digitalRead, IO25
 *     (ADC2_CH8) / IO26 (ADC2_CH9) / IO27 (ADC2_CH7) are driven. DS-C Appendix A
 *     Table IO_MUX gives those alternate analogue functions; none is selected,
 *     so the WiFi/ADC2 conflict does not reach them.
 *
 * ─────────────────────────────────────────────────────────────────────────────
 * §2  STRAPPING PINS, TESTED RATHER THAN ASSERTED.
 *
 *     DS-M §4 names five: GPIO0, GPIO2, MTDI (=GPIO12), MTDO (=GPIO15), GPIO5.
 *     DS-M Table 4 gives the level each one takes with nothing on it, because
 *     "the default values of the strapping pins ... are determined by pins'
 *     internal weak pull-up/pull-down resistors at reset if the pins are not
 *     connected to any circuit".
 *
 *     Working the actual boot state out of the netlist, pin by pin:
 *
 *     GPIO0  (mod 25) net IO0 -> J6.6 and nothing else. No resistor, no cap, no
 *            transistor on the net. With the programmer unplugged the pad sees
 *            only its own pull-up: DS-C IO_MUX row 23 gives GPIO0 "At Reset:
 *            oe=0, ie=1, wpu", DS-M Table 4 gives default 1. DS-M Table 6:
 *            GPIO0 = 1 -> SPI Boot Mode, GPIO2 "any value". So it boots from
 *            flash. With the programmer plugged in, its DTR/RTS pair drives IO0
 *            low and EN low to enter Joint Download Boot — which is the point of
 *            the header. VERDICT: correct both ways. Firmware never configures
 *            it; there is deliberately no IO0 constant in pins.h.
 *     GPIO2  (mod 24) absent from the netlist — unconnected. Internal pull-down,
 *            default 0 (DS-M Table 4; DS-C IO_MUX row 22 "oe=0, ie=1, wpd").
 *            DS-M Table 6 only consults GPIO2 when GPIO0 = 0, and in that case
 *            it needs 0, which is what it has. VERDICT: correct.
 *     GPIO12 (MTDI, mod 14) absent from the netlist — unconnected. Internal
 *            pull-down, default 0 (DS-M Table 4; DS-C IO_MUX row 18 "oe=0,
 *            ie=1, wpd"). DS-M §4.2: MTDI = 0 powers VDD_SDIO from VDD3P3_RTC,
 *            i.e. 3.3 V. The module's flash is a 3.3 V part, so 0 is the
 *            required value. This is the strapping pin that bricks a board when
 *            something pulls it up; nothing here can. VERDICT: correct.
 *     GPIO15 (MTDO, mod 23) absent from the netlist — unconnected. Internal
 *            pull-up, default 1 (DS-M Table 4; DS-C IO_MUX row 21 "oe=0, ie=1,
 *            wpu"). DS-M §4.3 Table 7: MTDO = 1 enables U0TXD boot printing,
 *            which is wanted — bring-up is over J6 and the ROM log is the first
 *            thing read. VERDICT: correct.
 *     GPIO5  (mod 29) absent from the netlist — unconnected. Internal pull-up,
 *            default 1 (DS-M Table 4; DS-C IO_MUX row 34 "oe=0, ie=1, wpu").
 *            DS-M §4.4 Table 8 uses MTDO+GPIO5 only for SDIO *slave* timing;
 *            this chip is never an SDIO slave. VERDICT: don't-care, and it has
 *            the documented default anyway.
 *
 *     So the sign-off's claim ("no pump gate or the buzzer lands on a strapping
 *     pin") is true — 25/26/27 are not strapping pins — but it is also the weaker
 *     half of the question. The half that matters is whether the five strapping
 *     pads reach the right level at reset, and all five do, four of them by
 *     being left unconnected on purpose and one by the programming header.
 *
 * ─────────────────────────────────────────────────────────────────────────────
 * §3  WHAT HAPPENS BEFORE THIS FUNCTION RUNS — the gap pinsInit() cannot close.
 *
 *     DS-C Appendix A Table IO_MUX, "At Reset" column:
 *       GPIO25 row 14: oe=0, ie=0    GPIO26 row 15: oe=0, ie=0
 *       GPIO27 row 16: oe=0, ie=0    GPIO14 row 17: oe=0, ie=0
 *     i.e. all four sit high-impedance with NO internal pull from reset until
 *     this function runs. Firmware therefore cannot be the thing that keeps a
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

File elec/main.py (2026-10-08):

"""The watering-backpack v2 main board — circuit, outline and placement.

    py -3.12 elec/main.py
    "C:/Program Files/KiCad/10.0/bin/python.exe" cadkit/pcbflow/finish.py elec/out/main

Design rationale lives in elec/CIRCUIT.md; this file is the executable version of
it. Where a number has a reason, the reason is beside it.

ONE RAIL SETS EVERYTHING: a Makita 18 V LXT pack is 21 V fresh and 15 V flat,
and it is the only supply on the board. So every part on VBAT is rated >= 40 V,
and the pump FETs >= 60 V so the inductive clamp has real margin. 24 V-max buck
parts (MP2315, AP63203) sit 4 V from a fresh pack before any switching spike and
are explicitly rejected.

NO H-BRIDGE: each pump runs ONE direction only — direction is chosen by which
pump is energised, not by polarity — so each needs a single low-side switch.
"""
from __future__ import annotations

import os
import sys

sys.path.insert(0, os.path.dirname(os.path.dirname(os.path.abspath(__file__))))

from cadkit.pcbflow import gen  # noqa: E402
from elec.quality_signoff import MANUAL as QUALITY_MANUAL  # noqa: E402

OUT_DIR = gen.begin(__file__)           # before skidl is imported — see gen.begin

from skidl import Net  # noqa: E402

# ── Design figures ──────────────────────────────────────────────────────────
VBAT_MAX = 21.0          # fresh Makita pack, OFF THE CHARGER
# ⚠ THIS WAS 20.0, AND THE SAME FILE ALREADY KNEW BETTER 25 LINES DOWN.
# An "18 V" LXT pack is a NAMEPLATE: 5 cells in series at 3.6 V nominal. The
# terminal voltage is 5 x 4.2 = 21.0 V off the charger and 5 x 3.0 = 15.0 V flat,
# and VBAT_MIN is already 15.0 -- so the design had committed to 5S at the bottom
# of the range while capping the top at a figure no 5S pack stops at. The ADC
# divider block below tabulates 15 V / 18 V / 21 V and states that "the whole
# 15-21 V range sits inside the ADC's characterised LINEAR band": the sense path
# was designed for 21 V and every OTHER margin in the file was taken at 20.
# What moves with it is recorded where it lands -- the freewheel diode's required
# Vf (the duty is 12/Vpack, so a FULL pack is the diode's worst case, not a flat
# one), R9's dissipation, and the docked-inrush energy. Nothing moves the wrong
# way: D1's SMCJ24A breaks down at 26.7 V minimum, so it still does not conduct
# at 21 V, and the hot-plug ring stays bounded by its 38.9 V clamp rather than by
# 2 x VBAT_MAX.
VBAT_MIN = 15.0          # flat
PUMP_A   = 7.5           # per pump, peak

# Battery sense divider: VBAT_MAX must land under 3.3 V at the ADC with margin --
# and "under 3.3 V" turned out to be the wrong test. Punchlist finding 33, reached
# independently by two validation passes: 100k/18k is 0.15254, which puts a fresh
# pack at 3.203 V against ADC1's 11 dB full scale of about 3.100 V. Nothing is
# damaged, Table 15 allows VDD + 0.3 -- but everything above ~20.3 V reads as the
# SAME saturated value, which is exactly the end of the range a "battery full"
# reading needs, and 3.05-3.20 V sits far above the 150-2450 mV characterised
# LINEAR band, so the reading is compressed before it is clipped.
#
# ⚠ AND THE ERROR IS IN THE DANGEROUS DIRECTION: compression reads the pack LOW,
# which RAISES the duty cap -- the same failure direction main.cpp's own clipping
# comment warns about. So this was never cosmetic.
#
# ⚠ THE BOTTOM LEG, NOT THE TOP, AND THAT IS THE WHOLE TRICK. Both passes proposed
# raising the top leg to 150k or 180k, which is the finding-22 trap: `100k` is ONE
# BOM line shared by R1, R20, R6 and R7, so moving R20 off it creates a SECOND line
# while 100k is still needed for the other three -- +1 line and ~$1.28 of feeder to
# fix a reading error. `18k` is R21 alone, so changing the bottom leg is
# value-for-value and the line count is identical.
#
# ⚠ 10k, NOT THE 12k FINDING 33 RECOMMENDED, AND IT IS BETTER ON EVERY AXIS. That
# finding tabulated 18k, 15k, 13k and 12k and stopped; it never looked below 12k.
#
#   divider      ratio    15 V    18 V    21 V    clamp 38.9 V
#   100k/18k   0.15254   2.288   2.746   3.203 X      5.934 X
#   100k/12k   0.10714   1.607   1.929   2.250        4.168 X
#   100k/10k   0.09091   1.364   1.636   1.909        3.536
#
# Three things fall out of that last row:
#   * the whole 15-21 V range sits inside the ADC's characterised LINEAR band
#     (0.150-2.450 V), which was finding 33's actual requirement;
#   * FINDING 36'S TRANSIENT STOPS BEING A TRANSIENT TO ARGUE ABOUT. The TVS's
#     clamped 38.9 V arrives at IO35 as 3.536 V, UNDER the pin's 3.601 V absolute
#     maximum -- where 12k leaves it at 4.168 V, still over, still needing the
#     "it is only microseconds" argument. This one needs no argument at all.
#   * 10k is a BOM line this board already has (R3), so the sense divider costs
#     nothing, and `18k` -- which was R21 alone -- disappears entirely.
#
# The price is ADC resolution and it is not a real price: 15-21 V spans 0.545 V,
# which at 12 bits over a 3.100 V full scale is about 120 counts per volt of pack,
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

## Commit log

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2026-09-12 firmware: make pump immune to joystick ADC noise; add WiFi/OTA debug
    The pump ran at a slow continuous trickle with the stick at rest. Measured
    cause: the joystick wiper carries ~120 counts RMS of noise (~7x a healthy
    pot) and the forward-only control law rectified it -- symmetric noise became
    a one-sided command, which the ramp integrator ratcheted up into a
    self-sustaining creep.
    Characterisation, via telemetry that samples every control loop (~200 Hz)
    rather than the 4 Hz the serial print could show:
    - noise is WHITE: hf/sd = 1.128, the exact ratio for uncorrelated Gaussian
    - excursions past the deadband last only 1-2 samples
    - amplitude is FLAT across stick travel and does not sc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
    [main.cpp]
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2026-09-30 firmware: slow the ramp so dwell time meters the dose
    With no proportional stick, the ramp IS the flow control: how long the stick
    is held sets how much water comes out. The previous rate reached full duty in
    ~106 ms, which is shorter than a human flick (150-250 ms), so every flick was
    a full-power burst that splashed small plants.
    Ramp is now 1000 ms from START_DUTY to full, ~9x slower:
    flick ~200 ms -> 79 (31%) ~400 ms -> 123 (48%)
    ~700 ms -> 189 (74%) 1000 ms+ -> 255 (full)
    START_DUTY (35, ~14%) is the duty the pump snaps to the instant it engages, so
    a flick lands ON the minimum useful flow rather than somewhere underneath it
    where nothing comes out. It sets the s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
    [main.cpp]
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2026-10-03 elec: generate the v2 main board -- routes clean, 0 unconnected
    elec/main.py is the executable form of elec/CIRCUIT.md: 43 parts, 140 x 100 mm,
    two layers, every part on the front for one assembly setup. ERC passes with 0
    errors (4 warnings are genuinely unused pins: the buck's RT and COMP, two driver
    NCs). The router now finishes with 0 unconnected nets.
    Board outline comes FROM the mechanical model as PCB_README requires, not from a
    guess: it lies flat on the frame's +X outer face, which is FRAME_D x DECK_Z =
    210 x 164, so 140 x 100 leaves ~35 mm all round for the shroud wall and its cable
    anchor. Terminals sit along one edge so every cable leaves the same face and the
    shroud's openings a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
    [cad_geom_check.py, fab.py, main.py]
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2026-10-03 elec: board reaches 0 unconnected, 0 violations, and the CAD gate passes
    main: 0 unconnected, 0 violation(s)
    4 cutout(s) match, 63.6 mm2 vs 63.6
    43 / 43 routed parts present in the CAD
    every routed part is where the CAD draws it
    Three faults, each found by the gate rather than by reading the board.
    TWELVE of the fourteen DRC violations were ONE footprint: KiCad's stock
    ESP32-WROOM-32E carries twelve 0.2 mm thermal vias, under the 0.3 mm fab
    minimum. elec/footprints/wbp.pretty/ now holds a local copy with fab-legal
    drills; nothing else about it is changed.
    The remaining violations were my placement, not the parts: pulling everything
    toward the edges to fix silk clearance cr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
    [cad_geom_check.py, main.py]
2026-10-03 cad: place the PCB from the ROUTED board and gate it against the assembly
    The frame now builds the board with Boards("elec/geom").solid("main") -- the
    routed geometry, never a typed placement. PCB_README is blunt about why: a
    hand-typed copy can only be checked against itself and always agrees, and it
    agreed while two connectors sat 0.54 mm short of a board edge.
    elec/cad_geom_check.py's _cad() is pointed at src.pump_frame.pcb_solid rather
    than left at the shipped BOARDS.solid(). As shipped it can only prove the geom
    loads and every part has a height; wired to the assembly it catches what the
    check exists for -- a board drawn where the routed one is not. It now reports
    "every routed part is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
    [cad_geom_check.py]
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2026-10-04 elec: re-lay the board at 95 x 100 to sit beside the battery
    The board is no longer sized to a printed frame's face -- that frame is lumber
    now. It is sized by the HOUSING's y budget: 210 mm of frame depth, minus the
    Makita dock's 100.6 across its slide, minus ~13 of printed wall and board
    clearance. 95 is the leftover, and the assert says so in those terms. 100 x 100
    also keeps it in JLCPCB's cheapest 2-layer tier.
    Parts only ever used 15% of the old 140 x 100, so area was never the problem.
    The bottom edge was: five terminals want 72.7 mm and 95 leaves ~72 clear of the
    corner holes, so the joystick and the programming header move to the TOP edge.
    The four that carry power or leave the pac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
    [main.py]
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2026-10-04 elec: the routed-board check was watching a board nothing places
    elec/cad_geom_check.py exists to catch "an assembly that draws the board
    somewhere the routed board is not". It was pointed at src.pump_frame.pcb_solid,
    which puts the board on the printed frame's +X face at x +189..+211. The build
    places src.housing.pcb_solid, at x -219..-197 -- the other side of the machine.
    Being precise about what that cost, because it is not what it looks like:
    cadkit.board_check is frame-invariant, and both copies were faithful rotations
    of the same geom, so the check was returning the right answer for the wrong
    reason rather than returning a wrong one. The hole it left is real though. The
    check DOES cat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
    [cad_geom_check.py]
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2026-10-04 fw: cap the duty to the pack voltage -- the pumps were seeing 20 V
    elec/CIRCUIT.md section 1: "Duty is capped in firmware to synthesise 12 V from
    an 18-20 V pack. PWM already chops the supply, so the motor does not care --
    but the cap must track the pack voltage, which is what the divider below is
    for." Section 4 gives the divider two jobs: "hold effective pump voltage
    constant as the pack sags, and expose sag in telemetry. This would have
    diagnosed v1's mid-run slowdown in thirty seconds."
    Neither job was being done. RUN_DUTY was PWM_MAX, so every engage put the whole
    pack across a 12 V pump -- 1.7x rated on a fresh one, continuously. R20/R21
    (100k/18k into IO35, C11 across the bottom leg)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
    [main.cpp]
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2026-10-04 fw: the tank-full alarm -- both halves of it were provisioned and unread
    elec/CIRCUIT.md section 5 buys a buzzer for one job: "Filling happens with the
    pump OFF and the user standing at the tank." DESIGN_V2 section 7 buys the sensor
    for the other half and says why it sits BELOW the full line: "False positives
    are cheap (stop early, look, carry on) but a false negative means overflow."
    Neither pin was read. IO14 and IO27 were on the board doing nothing.
    POLARITY WAS THE WHOLE RISK, so it is not a guess. Getting it backwards gives an
    alarm that is silent during the one event it exists to catch. elec/main.py
    shorts the sensor's MODE wire to GND, and MODE-to-GND selects the part's
    NORMALLY-CLOS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
    [check_level_alarm.py, main.cpp]
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2026-10-04 elec: nothing checked that the firmware and the board agree on a single pin
    Six signals are typed twice -- as *_PIN constants in firmware/src/main.cpp and
    as u_mcu["IOnn"] in elec/main.py -- and nothing connected the two files. They
    agreed only because somebody checked once; elec/main.py still carries the
    comment "Joystick on IO34 and pumps on IO25/IO26 match the firmware already
    running". A one-character drift on either side is silent: the board fabs, the
    firmware flashes, and a feature is dead on arrival.
    tools/check_pin_map.py reads BOTH sides from their own source -- no GPIO number
    is retyped in it -- and the correspondence table is the one place the two
    domains are tied together, which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
    [check_pin_map.py]
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2026-10-04 elec: CIRCUIT.md's pin table is now a third source, not documentation
    I wrote that table by hand earlier today -- generated fact, written out, with
    nothing checking it. That is the same liability the last two commits were about,
    and both of those tables had gone stale within a day of the edits that moved
    them. Better to close the loop on this one before it drifts than after.
    check_pin_map.py already read the firmware's *_PIN constants and elec/main.py's
    u_mcu[] wiring. It now reads CIRCUIT.md section 3 as well and requires all three
    to agree, including the module PIN NUMBER, which it resolves by inverting
    elec/main.py's own footprint dict rather than trusting the table's column.
    Verified b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
    [check_pin_map.py]
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2026-10-04 elec: the board could not be measured, and could not be checked
    Punch-list item 9. Ten net-labelled bring-up pads, and the gate the audit's
    own conclusion asked for: nothing in the pipeline checked a pin map or a
    voltage, so nothing could have caught the gate driver that was wrong on four
    of five pins.
    The pads: GND, VBAT, +3V3, VGATE, SW, GATE_A, GATE_B, VBAT_SENSE, JOY_FILT,
    LEVEL -- bare copper, no part, no placement, labelled with the NET name
    because GATE_A is what you read with a probe in one hand. Three of them are
    the measurement that confirms an earlier finding was really fixed rather than
    fixed in the source. Four have no exposed front copper of their own and get a
    close_last stub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
    [check_ic_pinouts.py, check_pin_map.py, close_last.py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]
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2026-10-04 Squashed 'cadkit/' changes from 30f30e4..bc36d86
    bc36d86 PCB quality A2: when a failing supply pin is fixed and when it may be exempted
    git-subtree-split: bc36d86e519d672fc5c670b24403f5582be8a7f7
    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
    [quality.py]
2026-10-04 Squashed 'cadkit/' changes from bc36d86..63cacbc
    63cacbc PCB quality: hard and soft findings, and when a soft rule may be broken
    git-subtree-split: 63cacbc80705d5c3da9573479217ae1a17e2ef23
    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
    [quality.py]
2026-10-04 elec: the buck had no input capacitor, and 7.5 A was on 1.2 mm of copper
    bronner's PCB quality pass landed in cadkit (pcbflow/quality.py,
    PCB_QUALITY.md). Run against this board it opened with 21 FAIL. This takes it
    to 5, and the five that are left are one problem, named below.
    WHAT IT FOUND THAT MATTERS
    The buck had NO ceramic input capacitor. SNVSAA5B asks for one at VIN "as
    close as possible to the VIN and GND pins"; this board had C1/C2, two 100 uF
    electrolytics, THIRTY-EIGHT MILLIMETRES away. At 500 kHz that loop is about
    40 nH and it rings VIN on every edge, on a part rated 40 V fed from a 20 V
    pack. C15, 4u7/50V, now sits on U1's own pins.
    The ESP32's decoupling was 35.6 mm from th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
    [main.py]
2026-10-04 cadkit: a pour can only carry current if the check can see it reach a pad
    Two fixes, both found by trying to put 7.5 A on a 2-layer board.
    layout.py: a zone could only ever be the whole board less an inset. That is
    the only shape a ground plane needs, so it is the only shape it grew, but it
    means no supply but ground can be poured -- and A1 wants 3.18 mm for 7.5 A at
    a 20 C rise, which is not a track. "zones" now also takes a dict with "poly"
    (an explicit outline) and "priority" (which of two overlapping pours wins the
    contested copper, so a small rail region can sit inside a larger one without
    the author cutting the hole by hand). The three-tuple still means what it did.
    A degenerate outli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
    [fab_package.py, quality.py]
2026-10-04 elec: the 7.5 A nets are pours now, and the board is quality-clean
    main: 0 unconnected, 0 violations | quality: 0 FAIL, 38 OPEN
    A1 failed five supply paths and every one said the same thing: the router had
    taken VBAT, PUMP_A_LO or PUMP_B_LO through a 0.67 mm via barrel. A 0.3 mm
    drilled via carries about 1-1.5 A. These nets carry 7.5. No track width fixes
    that -- 3.2 mm was already the IPC-2221 answer and it still failed, because a
    track is only as wide as the narrowest thing on it.
    So the three high-current nets never change layer at all. Each is an F.Cu pour,
    and the bottom half of the board was rebuilt so those pours can be laid without
    crossing each other or a signal:
    * the three VB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
    [main.py, route.py]
2026-10-04 housing: the Z stops were typed beside a chase that is derived
    Every gate green: board 0 unconnected / 0 violations / 0 quality FAIL, and all
    ten CAD gates pass.
    The cable chase is derived from the routed terminal blocks (_edge_connector_span)
    and the Z stops that hold the laminate down were a flat 10 mm in from each end
    of the board. Re-laying the bottom edge widened the chase and left the +Y stop
    sitting over the opening. The assert caught it, which is the system working --
    but an assert that fires every time the board is re-laid is a constant that
    should have been a derivation. A stop now takes what the chase leaves it, up to
    the 10 mm it wants: 10.0 mm at -Y and 5.6 at +Y.
    Deriving it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
    [main.py]
2026-10-04 Squashed 'cadkit/' changes from 63cacbc..7195078
    7195078 silk: a short board name, squarer name blocks, legible footprint text
    ea916d4 layout: grow plated pads whose annular ring is under the fab's minimum
    3a67ff7 kicad_silk: a label with no legible site is placed small, and reported
    fff67d7 kicad_silk: label solder jumpers by what they are for
    bc45fad finish: --keep-route re-runs everything after the route
    efdd75f quality: A12 measures the board against the fab's published minimums
    git-subtree-split: 71950784a430dbd883439922e2c82fd0cdf9198c
    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
    [finish.py, quality.py]
2026-10-04 cadkit: a paste dab is not copper, and A12 was measuring it as copper
    A12's pad-gap rule picked a layer with "F.Cu if the pad is on F.Cu else B.Cu",
    so an SMD pad with no copper at all fell through to B.Cu and was compared as
    though it were. KiCad's thermal-tab footprints are full of those: SOIC-8-1EP
    ThermalVias, DPAK and D2PAK all subdivide one big land into several F.Paste-only
    openings, so the stencil lays a controlled volume instead of one lake that
    floats the part. No F.Cu, no net, no number.
    On watering-backpack's main board that was 4 hard FAILs and the board was not
    orderable: U1's four paste dabs sit ON the exposed pad they subdivide, so the
    measured gap is zero, against a net the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
    [quality.py]
2026-10-04 elec: the buck inductor saturated below the regulator's own current limit
    SNVSAA5B 7.2.2.3, Output Inductor Selection, in these words: "The inductor
    current rating must be higher than current limit", because "during an
    instantaneous short or over current operation event, the RMS and peak inductor
    current can be high". The LMR14020's high-side current limit is 2.5 / 3.2 /
    3.8 A min/typ/max (5.5 Electrical Characteristics).
    L1 was a Bourns SRN6045TA-150M: 15 uH, Isat 3.80 A TYP. Not above the limit --
    equal to it, and equal to the typical at that, so half the reel saturates below
    a fault the regulator is entitled to hold indefinitely. TI's own worked example
    in that same section pairs the sam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
    [main.py]
2026-10-04 elec: sign 25 of the manual quality items, and say what the other 13 lack
    The board sat at 38 OPEN manual items, which is the same as unaudited. It is
    now 0 FAIL / 13 OPEN, and the 13 are named rather than left as a count.
    Signed against primary sources, with the revision actually read: TI SNVSAA5B,
    TI SLUSAY4D, Espressif ESP32-WROOM-32E v2.1, Bourns SRN6045TA, Littelfuse
    SMBJ, Phoenix's MKDS and PT drawings, and JLCPCB's capability page. Where the
    evidence is a measurement it was taken off the ROUTED board, not derived from a
    typed placement -- island counts off the filled pours, graphics length off the
    placed footprints, pad-to-pad gaps by bisecting Collide.
    The sign-offs live in a new e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
    [main.py, quality_signoff.py]
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2026-10-04 elec: the ADC filter capacitors were 57 mm from the pins they filter
    M21 wants "the reference pin's capacitor at the pin". Measured on the routed
    board, C12 -- the joystick RC's capacitor, the only noise defence on an input
    fed by a hand-held stick on the end of a lead -- was 56.81 mm from U2.6 / IO34,
    and C11 was 28.04 mm from U2.7 / IO35. The placement block's own comment said
    "R21 and C11 sit at the MCU", which described an intention and not the board.
    That left ~57 mm of high-impedance track OUTSIDE the filter on the two signals
    that are this machine's entire input. C12 is now 2.19 mm from IO34 and C11
    2.35 mm from IO35, with R21 brought along to the tap it sets.
    R22 deliberately stays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
    [main.py, quality_signoff.py]
2026-10-05 elec: fuse the one wire that leaves the case, and stop ESP_RX back-powering 3V3
    M36 -- the only genuine safety finding in this audit. Three supplies leave this
    board down a cable, and the 3V3 pair are limited by the regulator itself: a
    short at J4 or J6 drives the LMR14020 into its own 2.5/3.2/3.8 A current limit
    with short-circuit protection and frequency fold-back, and the MCU resets. VBAT
    had nothing at all. J5's lead is the most exposed conductor in the machine -- it
    leaves the sealed bay through the chase and then climbs the OUTSIDE of the case
    to the tank, so it is the one wire that gets rubbed, pinched and walked past --
    and behind it is a Makita 18 V LXT pack that will put well over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
    [fab.py, main.py, quality_signoff.py]
2026-10-05 elec: the output capacitance was short once bias is allowed for, and the errata changed two of the buck's ratings
    M15, derived rather than taken on faith. SNVSAA5B 7.2.2.4's worked example ends
    "For stability consideration, one 47 uF output capacitor is needed at least",
    and that sentence has NO equation behind it and sits inside a 5 V / 2 A example
    -- so it is not a general floor anybody can check, and it is not what this board
    is sized against. Equations 11 to 14 at this board's own numbers are.
    The ceiling on undershoot is a BROWNOUT and not a preference: the ESP32's VDD33
    minimum is 3.0 V (WROOM-32E v2.1 table 14) against a 3.301 V rail, so 301 mV in
    total and 200 mV is that with margin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
    [main.py, quality_signoff.py]
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2026-10-05 elec: ten barrels were open under solder paste, and the board called them tented
    The gerber read carried on into the mask and paste layers. KiCad reports
    IsOnLayer(F_Mask) false for every via inside a pad -- it adds no mask
    opening of their own -- but the pad's aperture is already open over them,
    and the exported F.Mask settles it: 208 dark flashes, one per pad on the
    layer, zero clear flashes anywhere. No mask island inside any aperture.
    M29 was wrong in this repo in three ways, and measuring it properly is
    what found them. The sizes: Q1.3 and Q2.3 are 2.20 x 1.20, not the
    0.96 x 1.25 the note claimed, and the stitcher put vias there on purpose.
    The metric: by pad area the worst reads 8 %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
    [finish.py, quality.py, quality_signoff.py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]
2026-10-05 Squashed 'cadkit/' changes from 7195078..b2742c3
    b2742c3 close_last: no second via where the net already has one
    5906a86 pcbflow: stitch vias keep their plane; closing step starts from an escape via
    6a063b1 pcbflow: closing step starts from loose ends and respects pad layers; A12 counts barrel volume
    367d77b freecad hub: a refresh that cannot reach the hub closes itself, not a second window
    d3ff0c5 layout: keep copper out from under a screw head (cutout head_d)
    c6013c5 quality A12: no via hole inside a soldered SMD pad
    git-subtree-split: b2742c3e6de0a7911ce2885797df8f817cc3be83
    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
    [close_last.py, finish.py, quality.py]
2026-10-05 elec: two items were open for numbers they did not need
    M25 and M16 were both waiting on a figure from outside this repo. Both
    turn out to depend on quantities that can be computed here, and the answer
    in each case is better than the figure they were waiting for.
    M25, the freewheel diode's junction temperature. It could not be computed
    because the diode is unsourced, so neither Vf nor RthJC is a read number --
    but that has the dependency backwards. Everything on the BOARD side is
    measurable, and what comes out is the Vf the part MUST have, which changes
    which part gets bought. Three of the numbers this item carried were wrong.
    The duty is not the user's: main.cpp says "NO INTERMEDIATE DUTY"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
    [fab.py, main.py, quality_signoff.py]
2026-10-05 elec: M37 cited a package the board had since replaced
    The sign-off quoted F.Cu 554 and B.Cu 191 from the gerbers read at the top
    of the session. Nine vias were retired or moved after that, and a cadkit
    sync changed layout.py, route.py and close_last.py, so those counts
    described a package that no longer existed. Re-read: F.Cu 544, B.Cu 198,
    F.Mask 208, F.Paste 178, B.Paste 0, F.Silk 2545, B.Silk 1116, Edge 12.
    The drill total did NOT move -- 127 before and after, 104 at 0.300 mm both
    times -- which is what a stale package looks like, so it is now
    cross-checked against the board rather than admired: 86 board vias plus 41
    pad holes (0.300 x 18, twelve in U2's thermal pad and six in U1's, plu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
    [quality_signoff.py]
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2026-10-05 elec: one connector family, and the last two unsourced values
    Every field terminal is now Ningbo Kangnex WJ500V-5.08-NP -- 2P on
    J1/J2/J3, 5P on J4, 4P on J5 -- on Phoenix MKDS-3 footprints. J4 and J5
    were 3.5 mm PT-1,5 push-ins; the user's requirement turned out to be any
    no-solder wire attachment with no preference between screw and spring
    cage, so the clamp-style argument that bought a second family stopped
    applying. WORK_V2_PUNCHLIST item 11 is resolved by that.
    The footprint is a Phoenix and the part is not, which is measured rather
    than assumed: the WJ500V pin is a 0.90 mm ROUND post, MKDS-3 drills 1.30
    (+0.40, inside IPC-2222's hand-solder band and tighter than the drawing's
    own 1.50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
    [cad_geom_check.py, fab.py, main.py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]
2026-10-05 elec: 0 OPEN. Reverse polarity held by D1 as a crowbar, not a series FET
    WORK_V2_PUNCHLIST item 10. Three documents promised a reverse-polarity
    P-FET the board does not have; the argument that made it optional -- "the
    Makita terminal is keyed" -- died when the inlet became J1, a screw
    terminal with two identical wires, and nobody went back to it. M10 was
    SIGNED carrying the sentence "Reverse polarity is not protected and does
    not need to be: the pack cannot be docked backwards". No gate here could
    catch that: every gate reads the BOARD and the claim lived in PROSE.
    The item's own framing was the bug. It read "add protection" as "add a
    SERIES element", which means splitting the VBAT pour int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
    [fab.py, main.py, quality_signoff.py]
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2026-10-05 elec: the 10 A fuse is on the board. 0 FAIL, 0 OPEN at 95 x 112
    F2, a Littelfuse 178.6165 FLR holder (LCSC C207061), taking the standard ATC
    blade already in a drawer -- McMaster 7460K45, 10 A, 32 V. The holder was
    picked to suit the fuse, so the blade is never a BOM line.
    WHY IT MATTERS AND NOT JUST WHERE IT SITS. Reverse polarity on this board is a
    CROWBAR: D1 shorts a reversed pack and something else has to open the circuit.
    That sum only balances if the board is fed through 115 A2s or less, and while
    the fuse was a holder spliced into the lead, "115 A2s or less" was a condition
    imposed on whoever wired it up and no gate could see it. On the laminate it is
    a board property.
    WHAT IT COST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
    [cad_geom_check.py, fab.py, main.py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]
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
